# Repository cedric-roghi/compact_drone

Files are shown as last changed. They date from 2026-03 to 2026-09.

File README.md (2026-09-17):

# compact_drone
compact contra rotating drone

Progress Update (17/09/26):
- I have been making further tuning and tweaking to the PID gains.
- Built a simple landing gear system out of wood and a 3D printed adapter to screw onto the drone frame.
- I have got some first flight attempts with the drone hopping around the garden in a semi-controlled way.

https://github.com/user-attachments/assets/63424fa8-df9c-4474-a59d-4073fd4611da

Progress Update (09/09/26):
- The yaw controls are working. I have found some PID gains that seem stable at low and high rotor speeds. I am planning on making a PyQT application to adjust flight controller settings without flashing the microcontroller.
- I used hot glue to fix the servo motors more securely and printed some new link rods to reduce play in the swash-plate.
- The swash-plate currently has too much play where the drone cannot correct error when its too small and leads to uncontrollable oscillation.

https://github.com/user-attachments/assets/415317f5-2f4a-4eaa-9d52-048ebe863607

## Table of Contents
- [Requirements](#requirements)
- [Rationale](#rationale)
- [Installation](#installation)
- [Usage](#usage)
- [Features](#features)
- [Future_Additions](#future_additions)
- [Configuration](#configuration)
- [Known_Issues](#known_issues)

## Requirements
- Software:
    - Freecad (for 3D part design)
    - KICAD (PCB design)
    - ST Cube IDE (ST account required for download)
- Hardware:
    - BOM to come
    - Access to a 3D printer

## Rationale
I did not come up with the design idea of a tube shaped coaxial drone. Despite it being a rare design I got inspiration from projects such as [backcountrydrones](https://www.youtube.com/watch?v=82phDhYGT_0) and [Tdrone](https://github.com/ShenZhenAccelerationTechCo/Tdrone). BackcountryDrones guys have now changed to Ascent Aerosystems and make military/law enforcement and industrial coaxial drones. The NASA mars copter is another example of a contra rotating drone design.

The idea is that the propellers can fold down which means the drone can fit in smaller storage solutions. Not only does the the tube shape enable a smaller size when storing the drone but it also helps make it more rugged and resistant to poor treatment. A final goal for this project would be to have a drone I can strap to the outside of a hiking pack without having to worry about damage. 

Using a coaxial design is more efficient in theory. Having two large propeller spinning about the center of the drone increases the lifting disc area compared to having four propellers next to each other that will waste space. A coaxial drone with a tube shape also reduces its surface area when tilting forwards to move making it more streamlined than a quadcopter that shows more surface area to drag when moving forward. I recommend reading this paper from Ascent Aerosystems about all the advantages and its got diagrams (https://ascentaerosystems.com/wp-content/uploads/2024/12/Coaxial-Advantage-White-Paper-Ascent-AeroSystems.pdf).

Just because two propellers are stacked on top of each other does not actually mean I get double the lift of normal helicopter. Based on a small amount of research I have done, it would seem that while coaxial drones can be more efficient and reduce turbulent airflow they do not multiply thrust by two. Basically the thrust gain is not linear. Source (https://www.ligpower.com/blog/conventional-vs-coaxial-drone-motors.html).

Figures from the Ascent Aerosystems paper (https://ascentaerosystems.com/wp-content/uploads/2024/12/Coaxial-Advantage-White-Paper-Ascent-AeroSystems.pdf).



Some applications for the drone would be for survey work in remote areas, filming, compact and rapid deployment via stackable launch cells. In theory it could even be launched from a plane like the Atlantique 2 which already has tube shaped launchers on the belly for sonars. The mass plane launch system could enable for massive detailed search areas using drone swarms for any use case that would require a search area like pest control, mountain rescue, security perimeters.

Atlantique 2 sonar buoys launcher.
Sonar_Buoys_Launcher_of_Breguet_Atlantic

- STM32f411:
    - Same MCU I used for my turret project. Its fast, powerful, and has many timers for pwm output. Since I used it for a previous turret project it makes the PCB development for the drone much faster.
    - Another great advantage of this MCU is that it can do up to 100MHz clock speed which gives me plenty of headroom for "high speed"(relative term) communications like UART or I2C, without preempting my critical FreeRTOS tasks.

Below are some pictures of the PCB and 3D design to be printed.
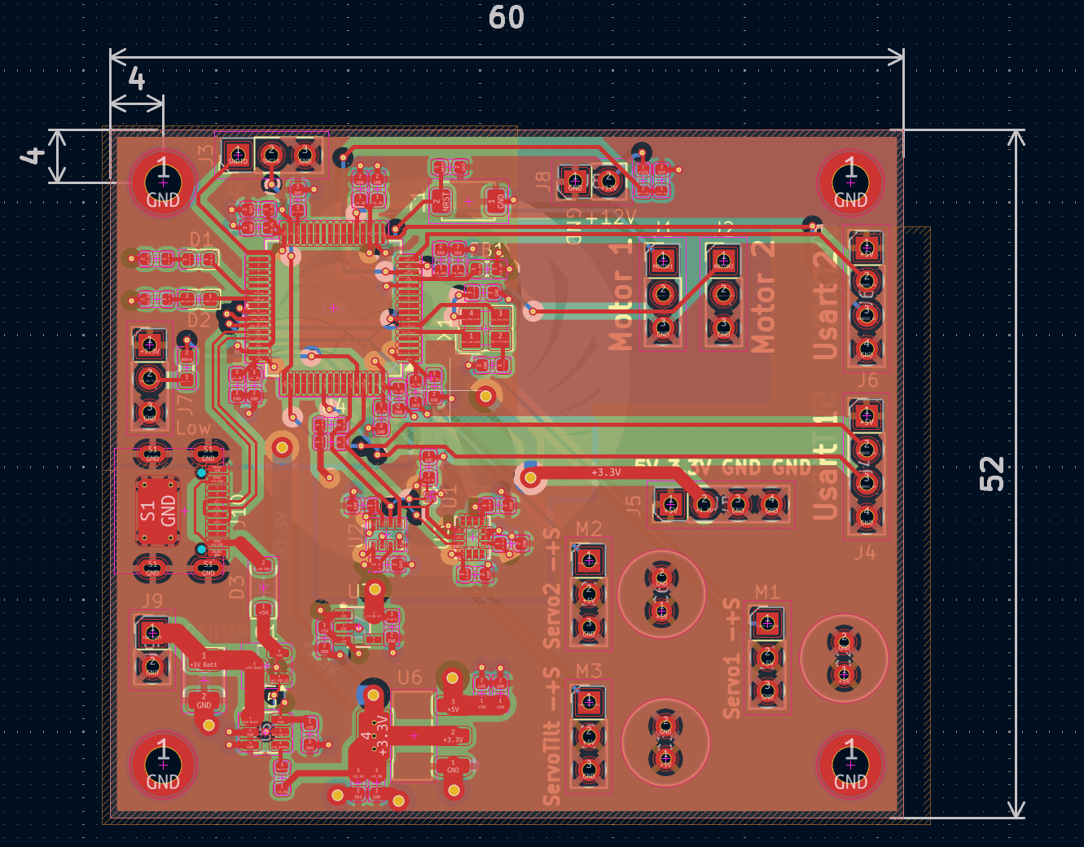
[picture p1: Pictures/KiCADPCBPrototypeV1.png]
Picture of Kicad PCB

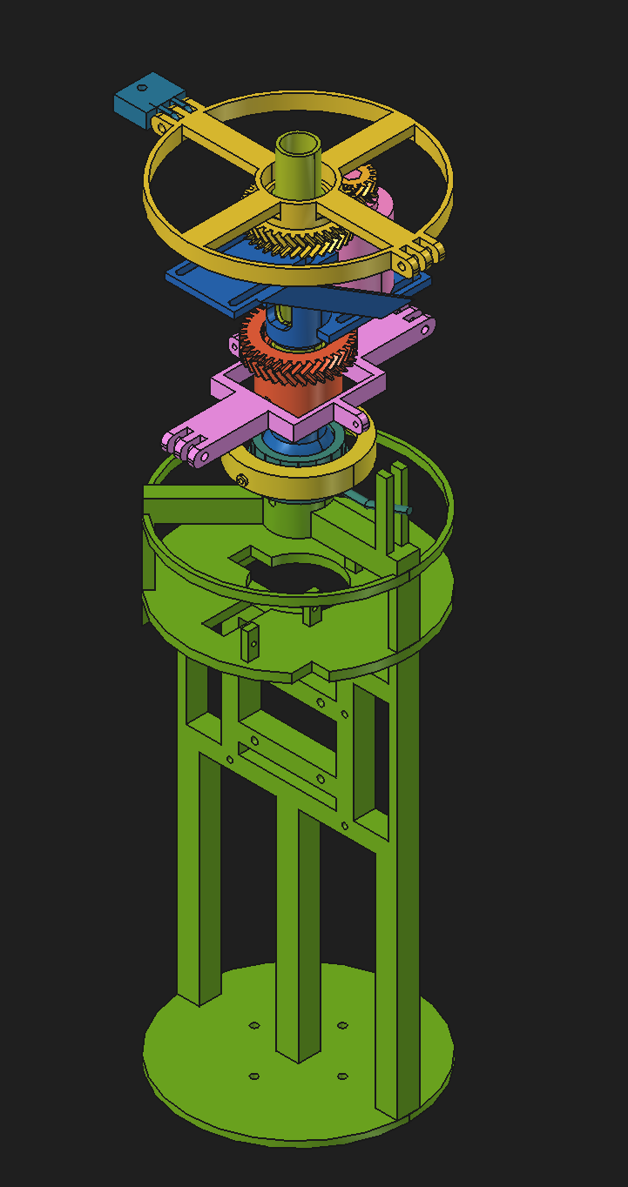
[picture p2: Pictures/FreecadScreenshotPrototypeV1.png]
Picture of FreeCAD design

electronics picture
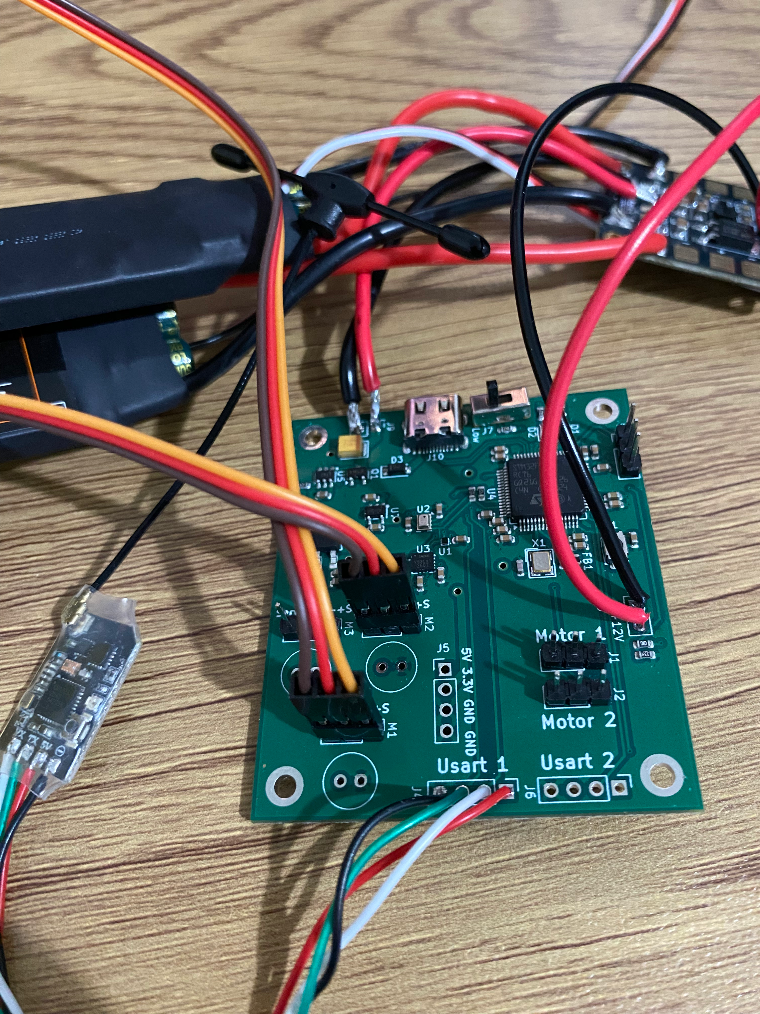
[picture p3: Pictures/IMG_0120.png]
electronics picture

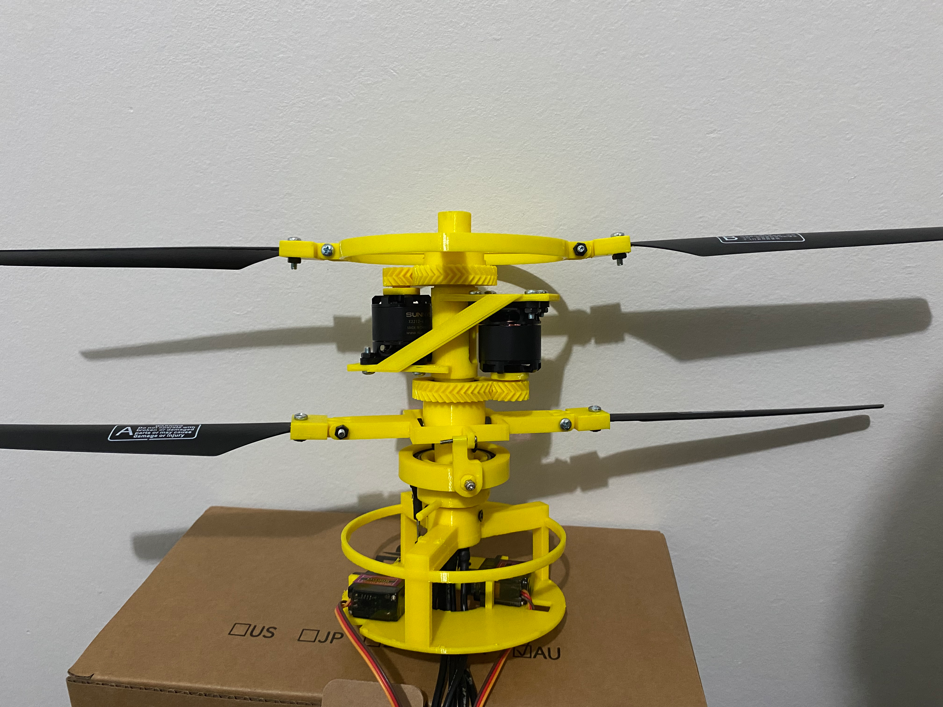
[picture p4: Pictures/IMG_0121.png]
electronics picture


## Installation
program command for usb in BOOT 0 mode

dfu-util -a 0 -s 0x08000000:leave -D build/debug/Drone_Code.bin

or use an stlinkv2.

## Usage

## Features
- Flight Controller
    -  ICM42605 IMU
    -  MMC5603NJ Magnetometer
    -  BMP280 Barometer
    -  2 USART connections for ELRS receiver and a future upgrade
    -  SWD connector for debugging/flashing
    -  Green and Red status LEDs
    -  BOOT0 switch (to switch bootloader mode)
    -  Reset button
    -  Extra servo PWM connector for camera pitch control (idea is that there is no need for yaw since the drone spins around easily)
 
- Mechanical
    - Foldable propellers
    - Fully 3D printed body
    - 
## Future_Additions

## Configuration

## Known_Issues

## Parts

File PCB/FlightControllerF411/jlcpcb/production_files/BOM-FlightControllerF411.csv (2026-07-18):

Comment | Designator | Footprint | LCSC | Quantity
100kΩ | R4 | R_0603 | C25803 | 1
100nF | C10,C13,C14,C15,C17,C19,C21,C22,C25,C30,C4,C5,C8 | C_0603 | C14663 | 13
100uF | C26 | C_CASE-B-3528-21(mm) | C16133 | 1
10k | R1 | R_0603_1608Metric_Pad0.98x0.95mm_HandSolder | C25805 | 1
10nF | C7 | C_0603 | C57112 | 1
10uF | C11,C27,C29,C31,C33 | C_0603 | C19702 | 5
18pF | C16,C18 | C_0603 | C1647 | 2
1uF | C23,C24,C28,C32 | C_0603 | C15849 | 4
2.2uF | C1,C9 | C_0603 | C23630 | 2
220Ω | R3 | R_0603 | C22962 | 1
270Ω | R2 | R_0603 | C22966 | 1
33kΩ | R5 | R_0603 | C4216 | 1
4.7kΩ | R6,R7 | R_0603 | C23162 | 2
4.7uF | C12,C20 | C_0603 | C19666 | 2
470kΩ | R8 | R_0603 | C23178 | 1
AMS1117 | U6 | SOT-223-3_L6.5-W3.4-P2.30-LS7.0-BR | C6186 | 1
AO3401A | Q1 | Q_SOT-23 | C15127 | 1
B5817W | D3 | D_SOD-123 | C7420328 | 1
BMP280 | U2 | Bosch_LGA-8_2x2.5mm_P0.65mm_ClockwisePinNumbering | C83291 | 1
Connector, USB-TYPE-C-16P | J10 | TYPE-C-SMD_HX-TYPE-C-16PIN | C2927039 | 1
ICM-42605 | U3 | LGA-14_L3.0-W2.5-P0.50-TL | C2655099 | 1
LTC4412xS6 | U5 | TSOT-23-6 | C514442 | 1
MMC5603NJ | U1 | FLIPCHIP-4_L0.8-W0.8-R2-C2-P0.40-TL | C404328 | 1
RT9013-33GB | U7 | SOT-23-5_L3.0-W1.7-P0.95-LS2.8-BL | C47773 | 1
STM32F411RCTx | U4 | LQFP-64_10x10mm_P0.5mm | C222222 | 1
Tactile Button, 160gf | S1 | SW_TS-1088-AR02016 | C720477 | 1
X322525MOB4SI | X1 | CRYSTAL-SMD_4P-L3.2-W2.5-BL | C9006 | 1
~ | FB1 | FB_0603 | C14709 | 1

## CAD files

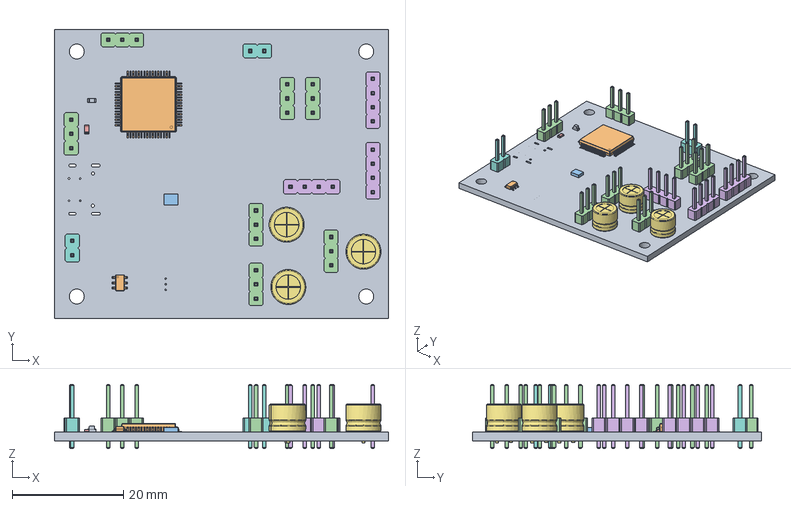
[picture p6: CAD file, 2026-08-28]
Mechanical/FlightControllerF.FCStd
60.0 x 52.0 x 11.5 mm
Pcb_b9f9
U4_LQFP-64_10x10mm_P0.5mm_fae24eecaddc
U2_Bosch_LGA_8_2x25mm_P065mm_ClockwisePinNumbering_f0a005fde938
J7_PinHeader_1x03_P254mm_Vertical_549c4d7b720a x 7
R1_R_0603_1608Metric_eb1ff95d47ac
J4_PinHeader_1x04_P254mm_Vertical_8452266c3579 x 3
C6_C_Radial_D63mm_H50mm_P250mm_8d51c2e56bce x 3
J8_PinHeader_1x02_P254mm_Vertical_0fda977fbcc8 x 2
D2_LED_0603_1608Metric_ebea01f88a53
U5_TSOT-23-6_ac6f2db5987e

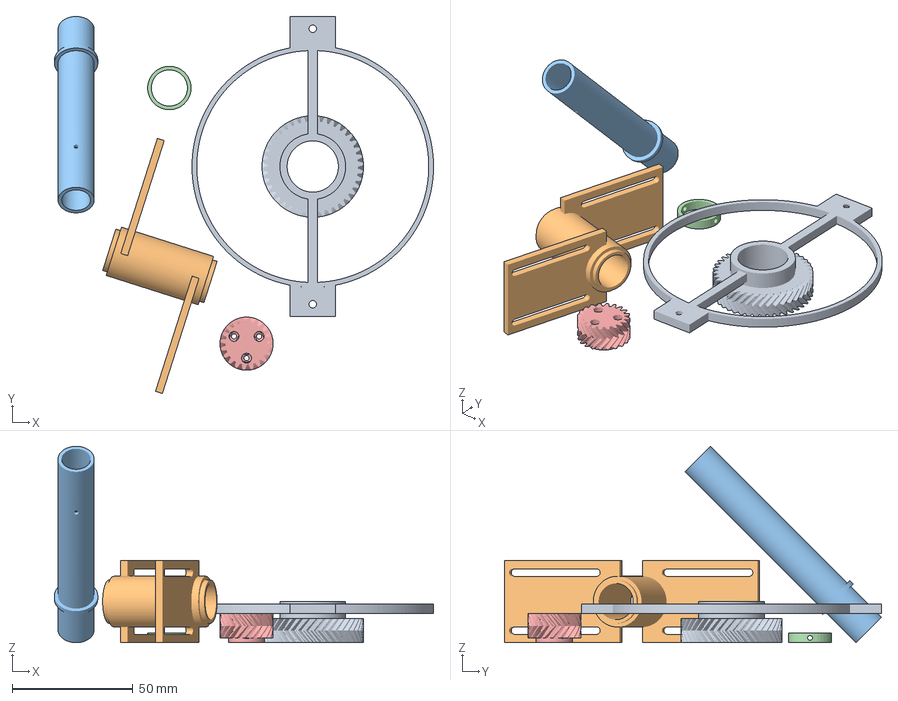
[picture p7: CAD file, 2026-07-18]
Mechanical/RotorShaftMechanical-Drone_Mechanical_UpperUpperGear.3mf
156.9 x 156.0 x 81.3 mm
RotorShaftMechanical-Drone_Mechanical_UpperUpperGear.stl
RotorShaftMechanical-Drone_Mechanical_UpperMotor Holder.stl
RotorShaftMechanical-Drone_Mechanical_UpperShaft.stl
RotorShaftMechanical-Drone_Mechanical_UpperBearingStopperUpper.stl
RotorShaftMechanical-Drone_Mechanical_UpperUpperMotorGear.stl

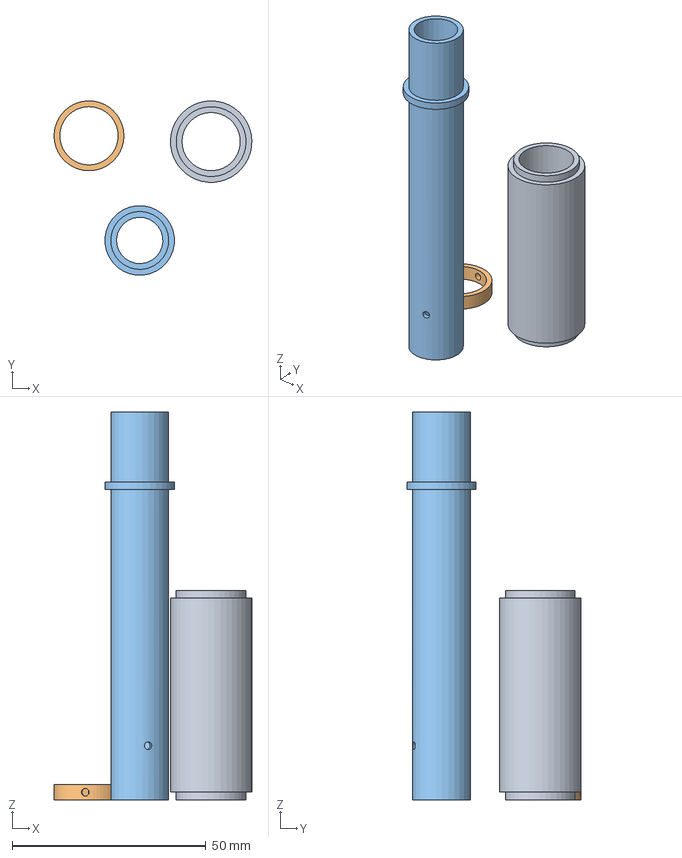
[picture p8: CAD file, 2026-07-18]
Mechanical/RotorShaftMechanical-Drone_Mechanical_UpperMotor Holder.3mf
51.0 x 44.9 x 100.0 mm
RotorShaftMechanical-Drone_Mechanical_UpperMotor Holder.stl
RotorShaftMechanical-Drone_Mechanical_UpperBearingStopperUpper.stl
RotorShaftMechanical-Drone_Mechanical_UpperShaft.stl

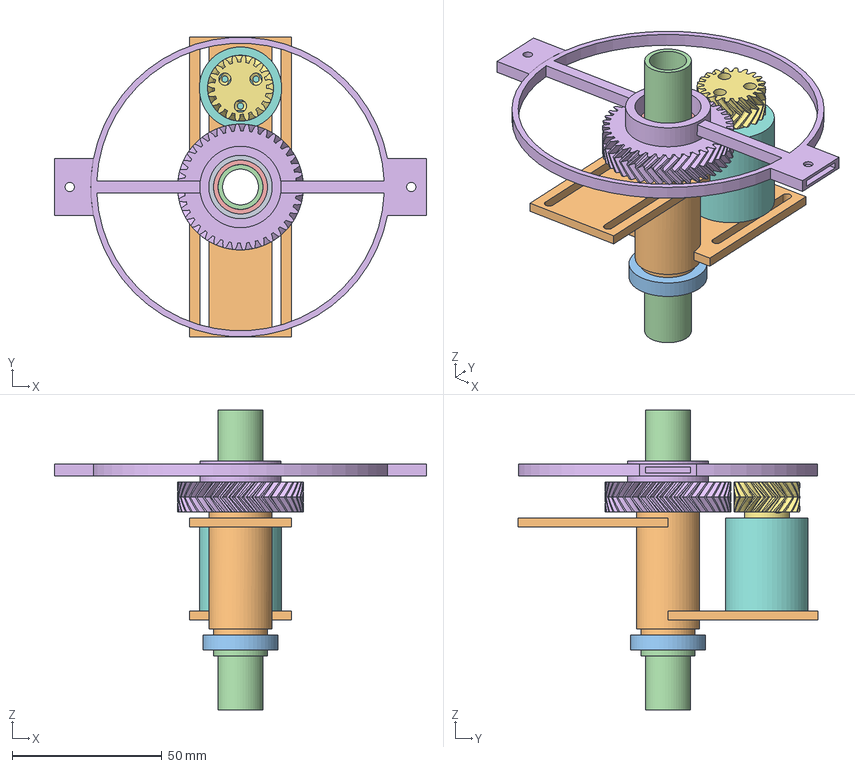
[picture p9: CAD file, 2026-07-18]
Mechanical/RotorShaftMechanical.FCStd
124.2 x 100.0 x 100.0 mm
BearingUpper
Motor Holder
BearingLower
Shaft
BearingStopperUpper
UpperGear
UpperMotorGear
Motor

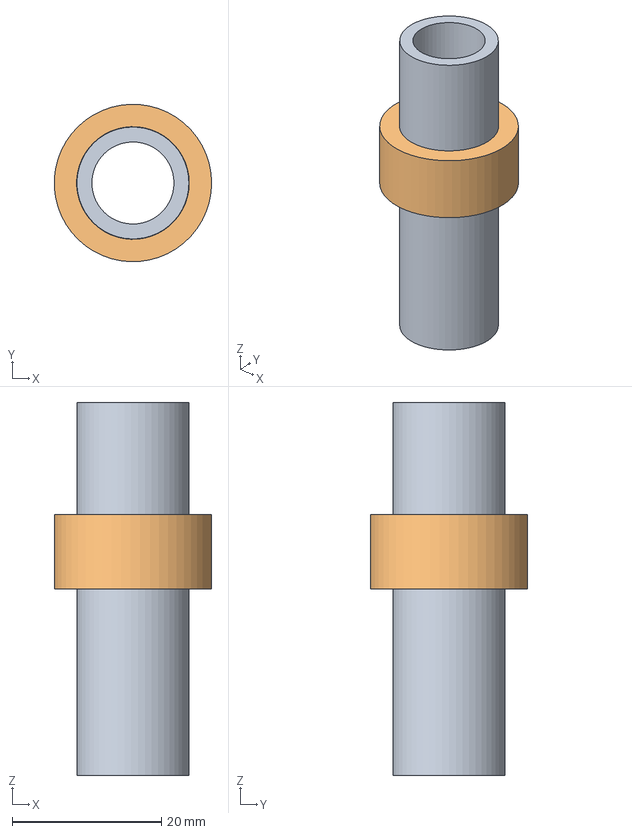
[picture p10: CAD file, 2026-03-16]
Mechanical/DroneDriveShaft.FCStd
21.1 x 21.1 x 50.0 mm
Main Shaft
BottomRotor

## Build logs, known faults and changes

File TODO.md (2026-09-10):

### Prototype V1 checklist

- ✅ PCB design done
- ✅ Drone mechanical structure done
- ✅ ELRS receiver connected and receiving
- ✅ Flight controller receiving packets from ELRS receiver
- ✅ ELRS transmitter receives telemetry packet from drone
- ✅ IMU (Just the accelerometer and gyroscope) is working and sensor fusion to get stable data
- ✅ Motor control file to limit motor operations within safe  physical ranges (ie. dont move servo more than swashplate can physically handle)
- 🚧 PID controllers for yaw, pitch and roll
- ⬜ Add magnetometer and barometer functionality to the flight controller code 
- ⬜ Persistent flight controller settings to be stored in stm32 flash memory
- ⬜ PyQT application to adjust flight controller settings without flashing the microcontroller.

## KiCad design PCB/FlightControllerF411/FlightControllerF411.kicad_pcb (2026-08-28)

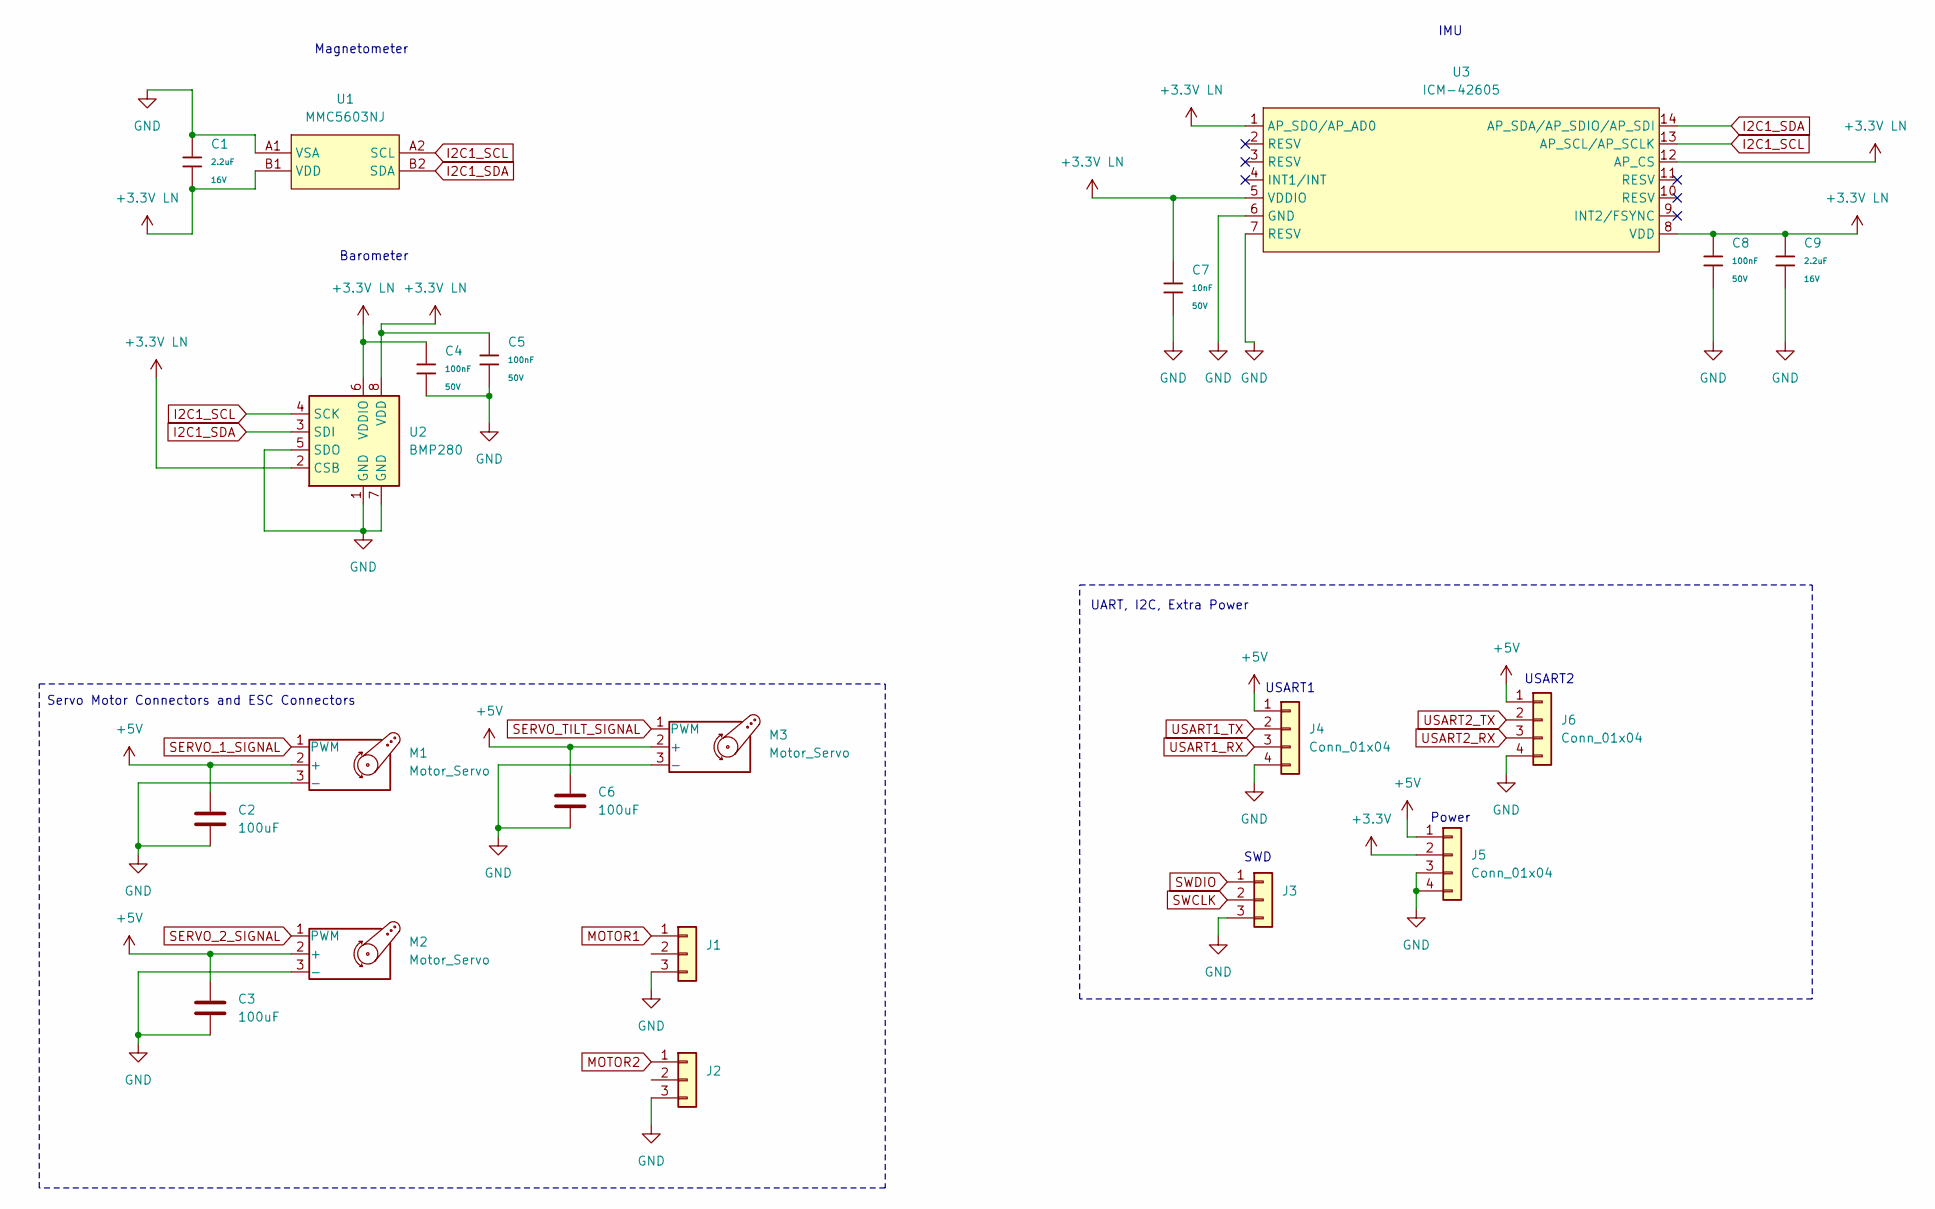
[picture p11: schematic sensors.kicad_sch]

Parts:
C1, C9: 2.2uF; C_0603; Voltage Rated 16V; Tolerance ±10%; Part CL10A225KO8NNNC; LCSC C23630
C2, C3, C6: 100uF; C_Radial_D6.3mm_H5.0mm_P2.50mm
C4, C5, C8: 100nF; C_0603; Voltage Rated 50V; Tolerance ±10%; Part CC0603KRX7R9BB104; LCSC C14663
C7: 10nF; C_0603; Voltage Rated 50V; Tolerance ±10%; Part 0603B103K500NT; LCSC C57112
J1, J2, J3: Conn_01x03; PinHeader_1x03_P2.54mm_Vertical
J4, J5, J6: Conn_01x04; PinHeader_1x04_P2.54mm_Vertical
M1, M2, M3: Motor_Servo; PinHeader_1x03_P2.54mm_Vertical
U1: MMC5603NJ; FLIPCHIP-4_L0.8-W0.8-R2-C2-P0.40-TL; MPN MMC5603NJ; LCSC Part C404328
U2: BMP280; Bosch_LGA-8_2x2.5mm_P0.65mm_ClockwisePinNumbering
U3: ICM-42605; LGA-14_L3.0-W2.5-P0.50-TL; MPN ICM-42605; LCSC Part C2655099

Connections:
+3.3V: J5.2; also elsewhere on the board
+3.3V LN: C1.2, C4.1, C5.1, C7.1, C8.1, C9.1, U1.B1 (VDD), U2.2 (CSB), U2.6 (VDDIO), U2.8 (VDD), U3.1 (AP_SDO/AP_AD0), U3.5 (VDDIO), U3.8 (VDD), U3.12 (AP_CS); also elsewhere on the board
+5V: C2.1, C3.1, C6.1, J4.1, J5.1, J6.1, M1.2 (+), M2.2 (+), M3.2 (+); also elsewhere on the board
GND: C1.1, C2.2, C3.2, C4.2, C5.2, C6.2, C7.2, C8.2, C9.2, J1.3, J2.3, J3.3, J4.4, J5.3, J5.4, J6.4, M1.3 (-), M2.3 (-), M3.3 (-), U1.A1 (VSA), U2.1 (GND), U2.5 (SDO), U2.7 (GND), U3.6 (GND), U3.7 (RESV); also elsewhere on the board
I2C1_SCL: U1.A2 (SCL), U2.4 (SCK), U3.13 (AP_SCL/AP_SCLK); also elsewhere on the board
I2C1_SDA: U1.B2 (SDA), U2.3 (SDI), U3.14 (AP_SDA/AP_SDIO/AP_SDI); also elsewhere on the board
MOTOR1: J1.1; also elsewhere on the board
MOTOR2: J2.1; also elsewhere on the board
SERVO_1_SIGNAL: M1.1 (PWM); also elsewhere on the board
SERVO_2_SIGNAL: M2.1 (PWM); also elsewhere on the board
SERVO_TILT_SIGNAL: M3.1 (PWM); also elsewhere on the board
SWCLK: J3.2; also elsewhere on the board
SWDIO: J3.1; also elsewhere on the board
USART1_RX: J4.3; also elsewhere on the board
USART1_TX: J4.2; also elsewhere on the board
USART2_RX: J6.3; also elsewhere on the board
USART2_TX: J6.2; also elsewhere on the board

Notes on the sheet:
USART1
Servo Motor Connectors and ESC Connectors
UART, I2C, Extra Power
Power
SWD
Magnetometer
Barometer
IMU
USART2

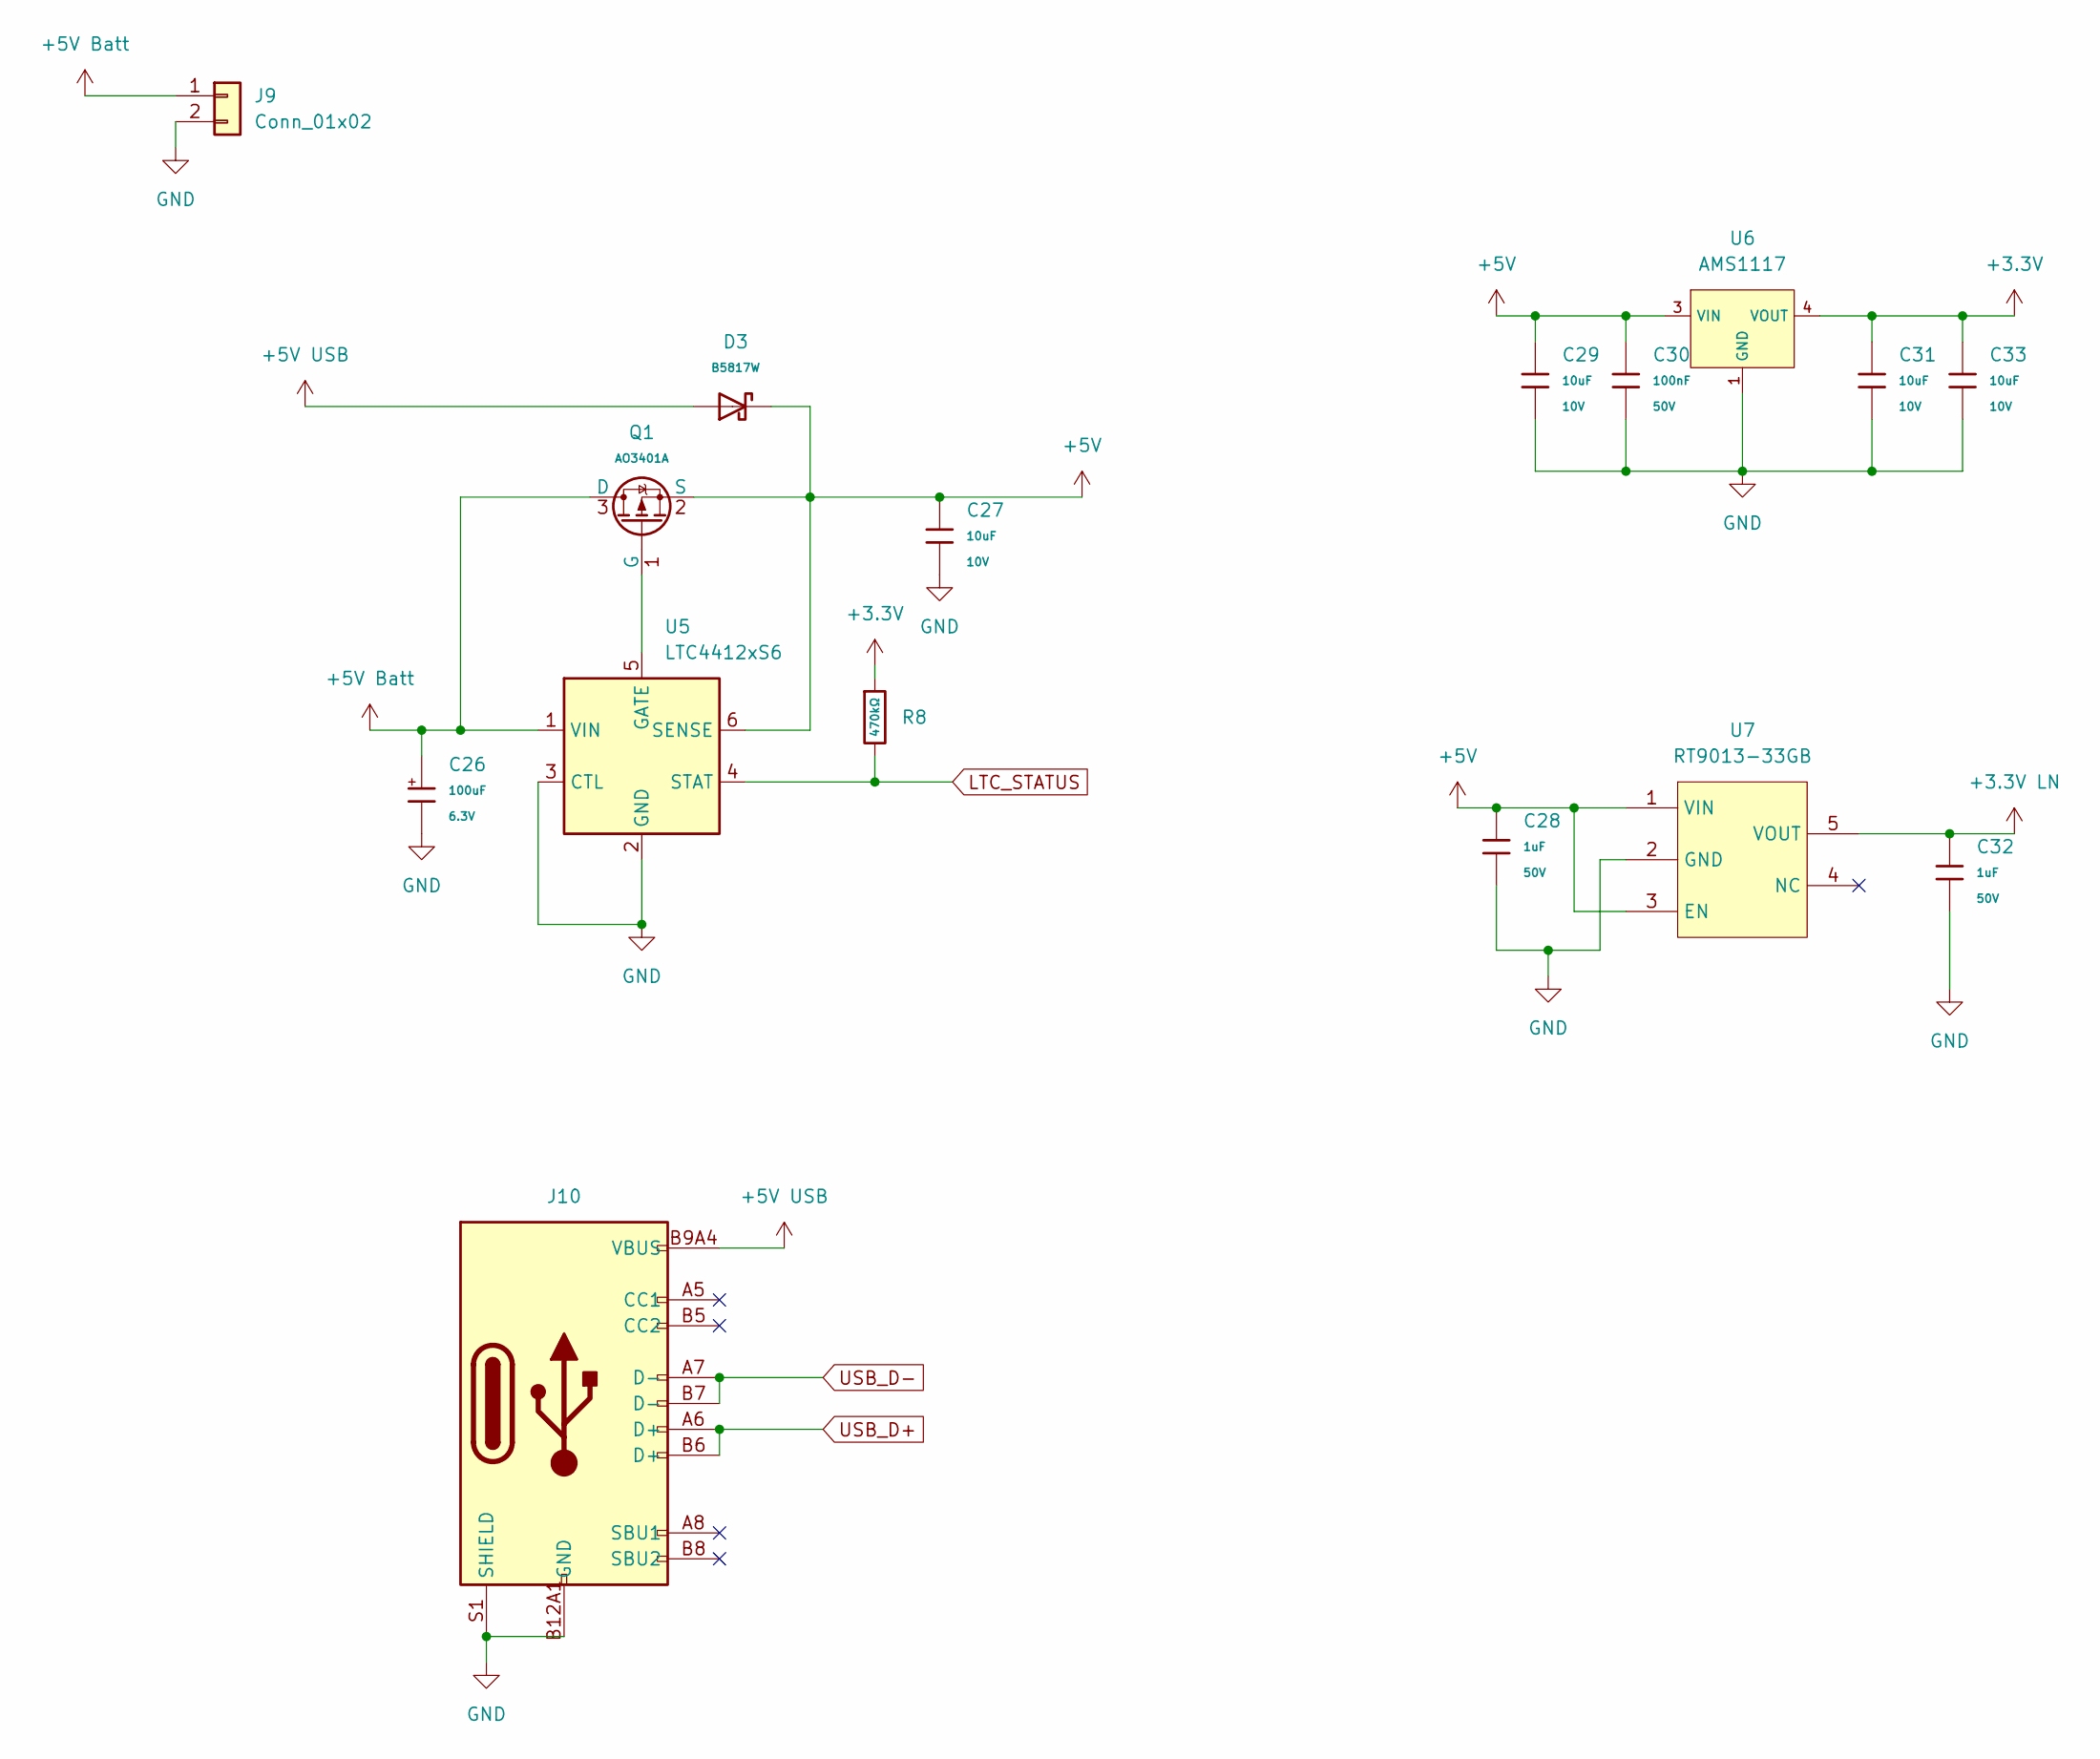
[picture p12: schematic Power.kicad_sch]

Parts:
C26: 100uF; C_CASE-B-3528-21(mm); Tolerance ±10%; Rated Voltage 6.3V; Part TAJB107K006RNJ; LCSC C16133
C27, C29, C31, C33: 10uF; C_0603; Voltage Rated 10V; Tolerance ±10%; Part CL10A106KP8NNNC; LCSC C19702
C28, C32: 1uF; C_0603; Voltage Rated 50V; Tolerance ±10%; Part CL10A105KB8NNNC; LCSC C15849
C30: 100nF; C_0603; Voltage Rated 50V; Tolerance ±10%; Part CC0603KRX7R9BB104; LCSC C14663
D3: B5817W; D_SOD-123; Forward Voltage (Vf@If) 0.45V@1.0A; Reverse Voltage (Vr) 20V; Part B5817W; LCSC C7420328
J9: Conn_01x02; PinHeader_1x02_P2.54mm_Vertical
J10: Connector, USB-TYPE-C-16P; TYPE-C-SMD_HX-TYPE-C-16PIN; LCSC C2927039
Q1: AO3401A; Q_SOT-23; Part AO3401A; LCSC C15127
R8: 470kΩ; R_0603; Overload Voltage (Max) 75V; Tolerance ±1%; Part 0603WAF4703T5E; LCSC C23178
U5: LTC4412xS6; TSOT-23-6
U6: AMS1117; SOT-223-3_L6.5-W3.4-P2.30-LS7.0-BR; Output Voltage 3.3V; Dropout Voltage 1.3V@(800mA); Part AMS1117-3.3; LCSC C6186
U7: RT9013-33GB; SOT-23-5_L3.0-W1.7-P0.95-LS2.8-BL; MPN RT9013-33GB; LCSC Part C47773

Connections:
+3.3V: C31.1, C33.1, R8.1, U6.2 (VOUT), U6.4 (VOUT); also elsewhere on the board
+3.3V LN: C32.1, U7.5 (VOUT); also elsewhere on the board
+5V: C27.1, C28.1, C29.1, C30.1, D3.1, Q1.2 (S), U5.6 (SENSE), U6.3 (VIN), U7.1 (VIN), U7.3 (EN); also elsewhere on the board
+5V Batt: C26.1, J9.1, Q1.3 (D), U5.1 (VIN)
+5V USB: D3.2, J10.A9B4 (VBUS), J10.B9A4 (VBUS)
GND: C26.2, C27.2, C28.2, C29.2, C30.2, C31.2, C32.2, C33.2, J9.2, J10.A12B1 (GND), J10.B12A1 (GND), J10.S1 (SHIELD), U5.2 (GND), U5.3 (CTL), U6.1 (GND), U7.2 (GND); also elsewhere on the board
LTC_STATUS: R8.2, U5.4 (STAT)
unnamed: Q1.1 (G), U5.5 (GATE)
USB_D+: J10.A6 (D+), J10.B6 (D+); also elsewhere on the board
USB_D-: J10.A7 (D-), J10.B7 (D-); also elsewhere on the board

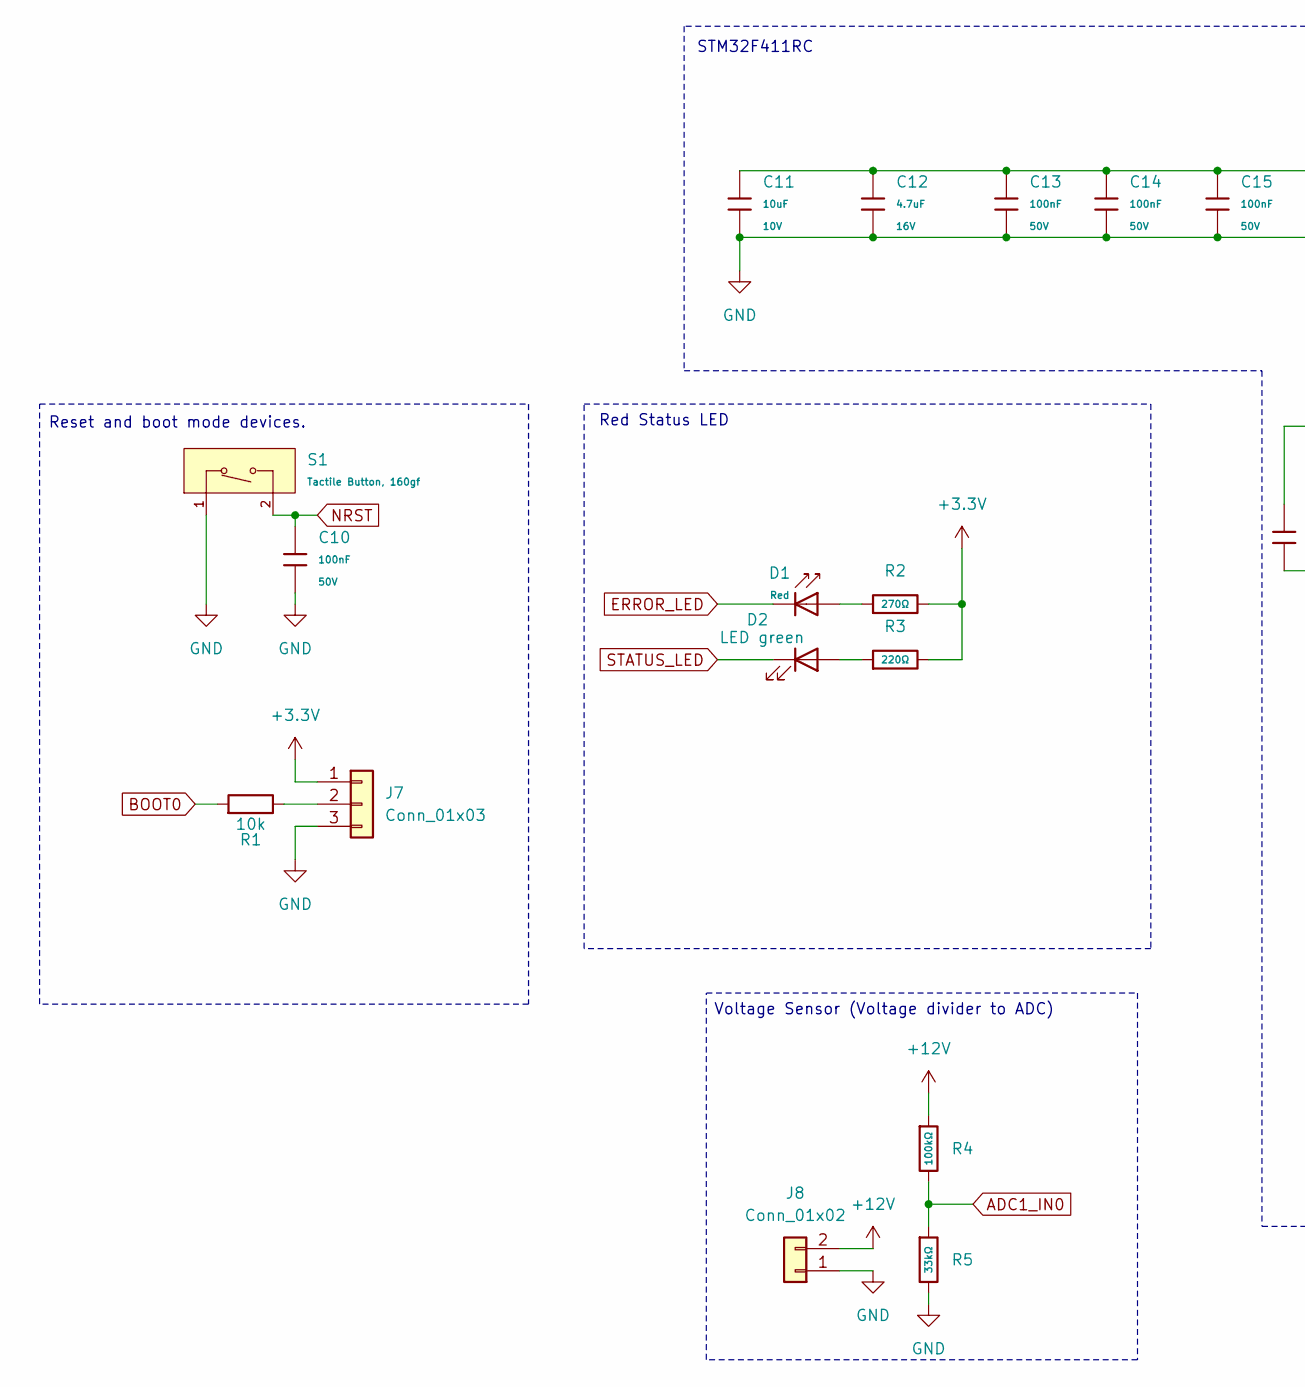
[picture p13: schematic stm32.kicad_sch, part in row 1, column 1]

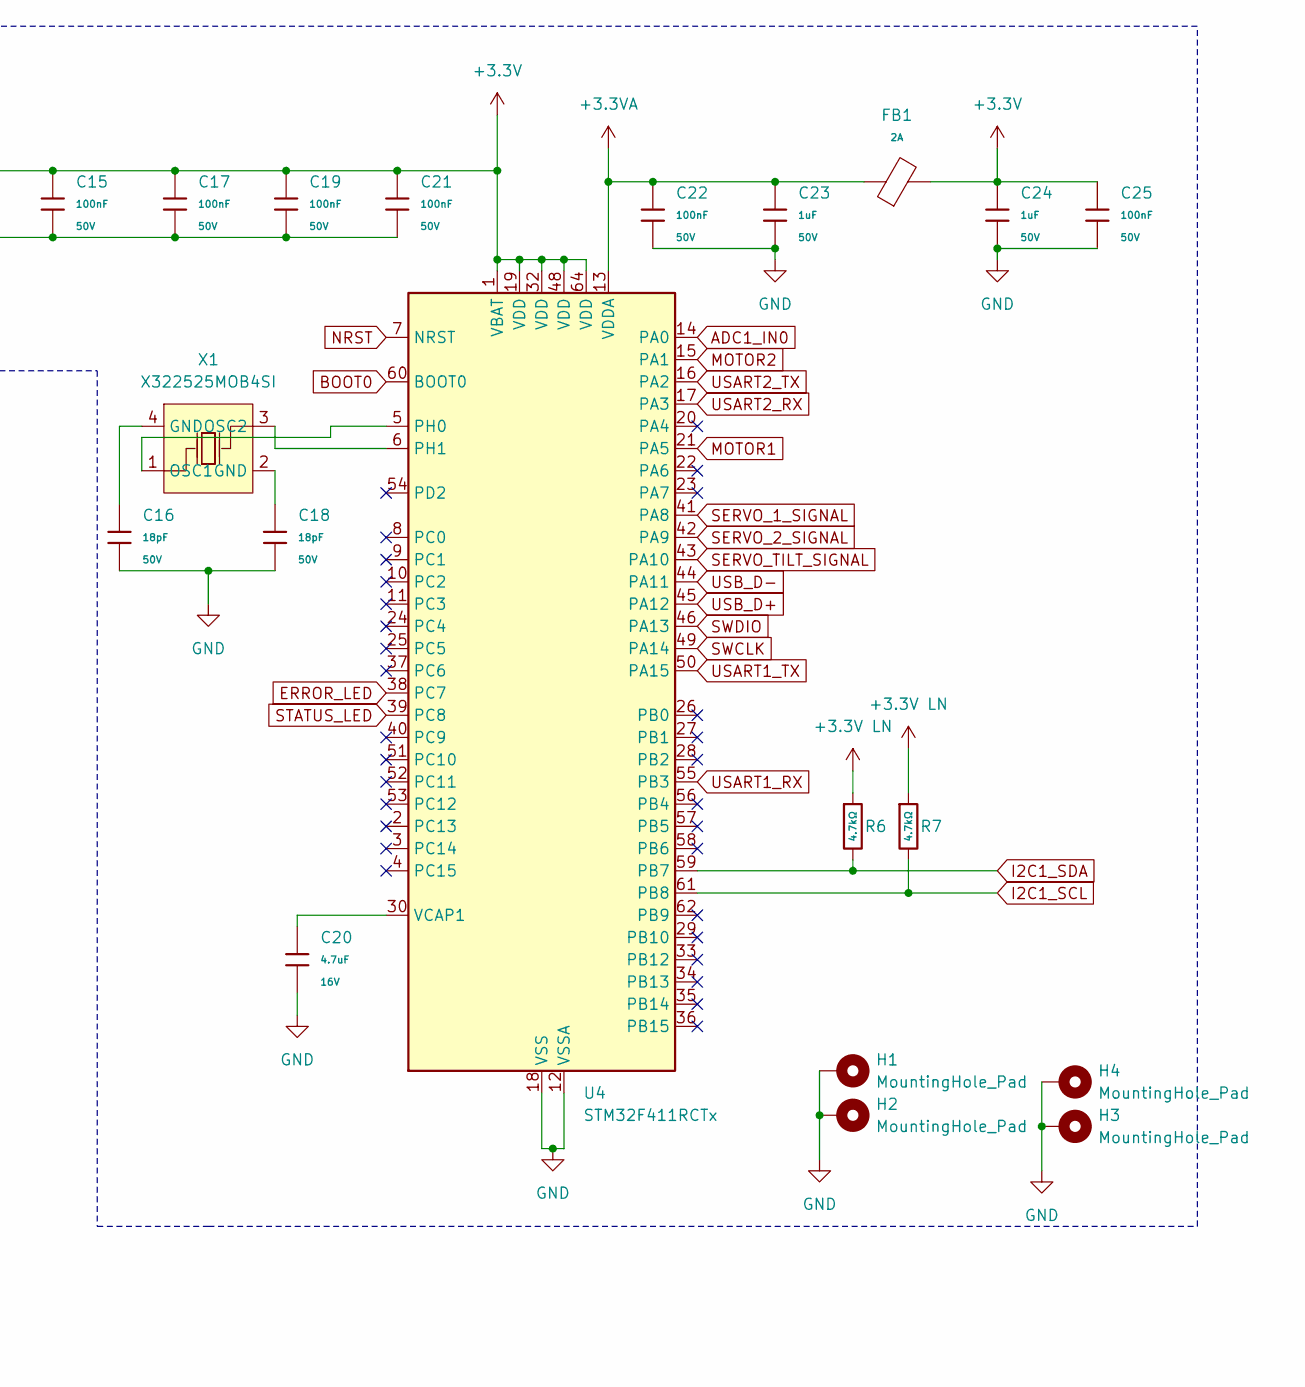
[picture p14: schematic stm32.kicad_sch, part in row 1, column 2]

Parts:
C10, C13, C14, C15, C17, C19, C21, C22, C25: 100nF; C_0603; Voltage Rated 50V; Tolerance ±10%; Part CC0603KRX7R9BB104; LCSC C14663
C11: 10uF; C_0603; Voltage Rated 10V; Tolerance ±10%; Part CL10A106KP8NNNC; LCSC C19702
C12, C20: 4.7uF; C_0603; Voltage Rated 16V; Tolerance ±10%; Part CL10A475KO8NNNC; LCSC C19666
C16, C18: 18pF; C_0603; Voltage Rated 50V; Tolerance ±5%; Part CL10C180JB8NNNC; LCSC C1647
C23, C24: 1uF; C_0603; Voltage Rated 50V; Tolerance ±10%; Part CL10A105KB8NNNC; LCSC C15849
D1: Red; D_0603; Part KT-0603R; LCSC C2286
D2: LED green; LED_0603_1608Metric_Pad1.05x0.95mm_HandSolder
FB1: FB_0603; Current Rating 2A; Tolerance ±25%; Part BLM18PG121SN1D; LCSC C14709
H1, H2, H3, H4: MountingHole_Pad; MountingHole_2.7mm_M2.5_DIN965_Pad
J7: Conn_01x03; PinHeader_1x03_P2.54mm_Vertical
J8: Conn_01x02; PinHeader_1x02_P2.54mm_Vertical
R1: 10k; R_0603_1608Metric_Pad0.98x0.95mm_HandSolder
R2: 270Ω; R_0603; Overload Voltage (Max) 75V; Tolerance ±1%; Part 0603WAF2700T5E; LCSC C22966
R3: 220Ω; R_0603; Overload Voltage (Max) 75V; Tolerance ±1%; Part 0603WAF2200T5E; LCSC C22962
R4: 100kΩ; R_0603; Overload Voltage (Max) 75V; Tolerance ±1%; Part 0603WAF1003T5E; LCSC C25803
R5: 33kΩ; R_0603; Overload Voltage (Max) 75V; Tolerance ±1%; Part 0603WAF3302T5E; LCSC C4216
R6, R7: 4.7kΩ; R_0603; Overload Voltage (Max) 75V; Tolerance ±1%; Part 0603WAF4701T5E; LCSC C23162
S1: Tactile Button, 160gf; SW_TS-1088-AR02016; Voltage Rating (Dc) 12V; Part TS-1088-AR02016; LCSC C720477
U4: STM32F411RCTx; LQFP-64_10x10mm_P0.5mm
X1: X322525MOB4SI; CRYSTAL-SMD_4P-L3.2-W2.5-BL; MPN X322525MOB4SI; LCSC Part C9006

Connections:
+3.3V: C11.1, C12.1, C13.1, C14.1, C15.1, C17.1, C19.1, C21.1, C24.1, C25.1, FB1.2, J7.1, R2.2, R3.2, U4.1 (VBAT), U4.19 (VDD), U4.32 (VDD), U4.48 (VDD), U4.64 (VDD); also elsewhere on the board
+3.3V LN: R6.1, R7.1; also elsewhere on the board
+3.3VA: C22.1, C23.1, FB1.1, U4.13 (VDDA)
+12V: J8.2, R4.1
ADC1_IN0: R4.2, R5.1, U4.14 (PA0)
BOOT0: R1.2, U4.60 (BOOT0)
ERROR_LED: D1.1, U4.38 (PC7)
GND: C10.2, C11.2, C12.2, C13.2, C14.2, C15.2, C16.2, C17.2, C18.2, C19.2, C20.2, C21.2, C22.2, C23.2, C24.2, C25.2, H1.1 (1_1), H2.1 (1_1), H3.1 (1_1), H4.1 (1_1), J7.3, J8.1, R5.2, S1.1 (A), U4.12 (VSSA), U4.18 (VSS), U4.31 (VSS), U4.47 (VSS), U4.63 (VSS); also elsewhere on the board
I2C1_SCL: R7.2, U4.61 (PB8); also elsewhere on the board
I2C1_SDA: R6.2, U4.59 (PB7); also elsewhere on the board
MOTOR1: U4.21 (PA5); also elsewhere on the board
MOTOR2: U4.15 (PA1); also elsewhere on the board
NRST: C10.1, S1.2 (B), U4.7 (NRST)
unnamed: C16.1, X1.4 (GND)
unnamed: C18.1, X1.2 (GND)
unnamed: D1.2, R2.1
unnamed: D2.2 (A), R3.1
unnamed: J7.2, R1.1
unnamed: U4.5 (PH0), X1.1 (OSC1)
unnamed: U4.6 (PH1), X1.3 (OSC2)
unnamed: C20.1, U4.30 (VCAP1)
SERVO_1_SIGNAL: U4.41 (PA8); also elsewhere on the board
SERVO_2_SIGNAL: U4.42 (PA9); also elsewhere on the board
SERVO_TILT_SIGNAL: U4.43 (PA10); also elsewhere on the board
STATUS_LED: D2.1 (K), U4.39 (PC8)
SWCLK: U4.49 (PA14); also elsewhere on the board
SWDIO: U4.46 (PA13); also elsewhere on the board
USART1_RX: U4.55 (PB3); also elsewhere on the board
USART1_TX: U4.50 (PA15); also elsewhere on the board
USART2_RX: U4.17 (PA3); also elsewhere on the board
USART2_TX: U4.16 (PA2); also elsewhere on the board
USB_D+: U4.45 (PA12); also elsewhere on the board
USB_D-: U4.44 (PA11); also elsewhere on the board

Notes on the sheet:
Red Status LED
STM32F411RC
Voltage Sensor (Voltage divider to ADC)
Reset and boot mode devices.

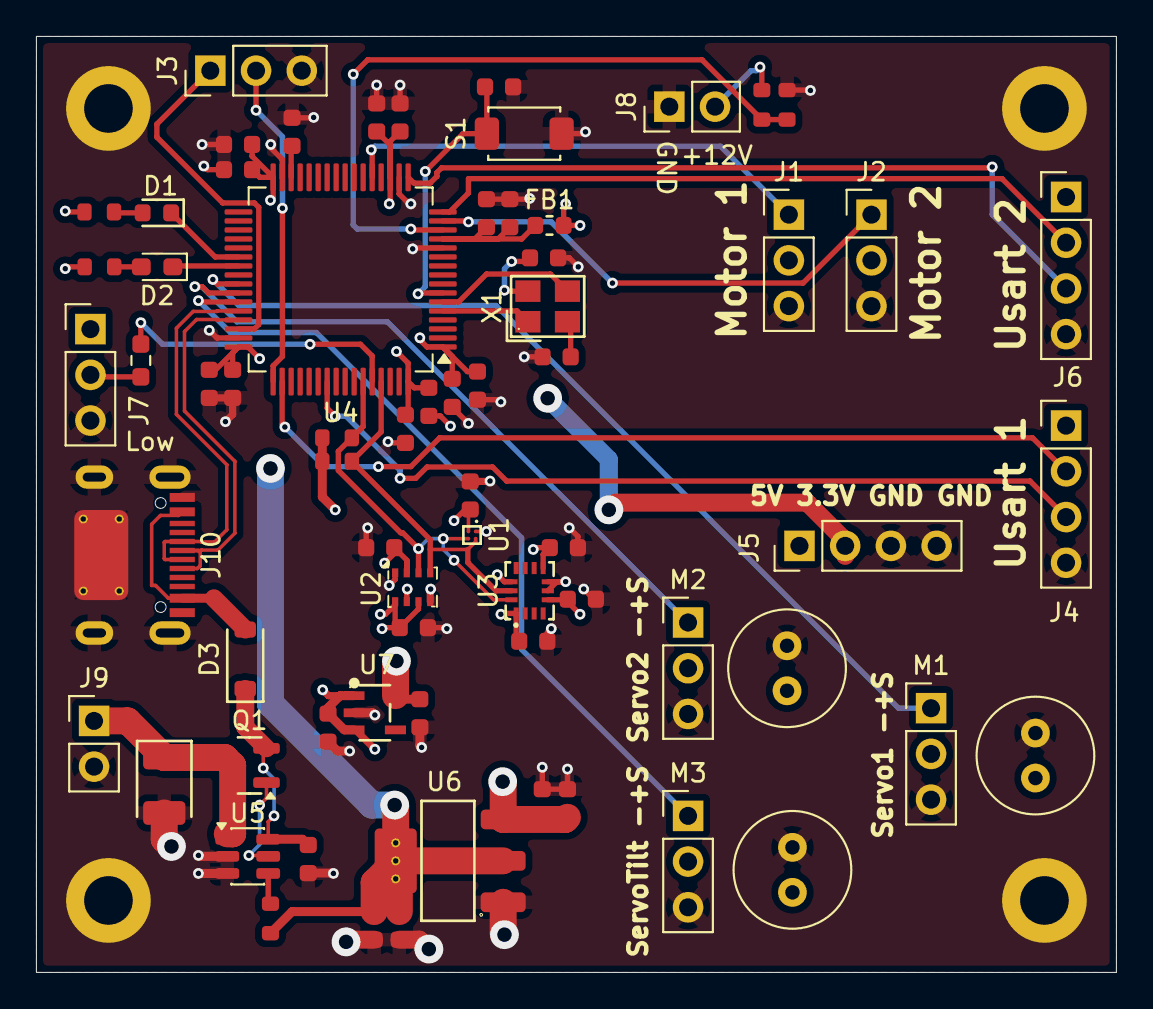
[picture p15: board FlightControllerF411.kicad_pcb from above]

Board: 4 copper layers, 60.0 x 52.0 mm, 72 parts (0 on the bottom side), 38 nets.

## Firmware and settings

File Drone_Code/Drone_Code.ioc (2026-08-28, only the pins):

Mcu.UserName=STM32F411RCTx
PA0-WKUP.Signal=ADCx_IN0
PA1.GPIO_Label=Motor 2
PA1.Signal=S_TIM2_CH2
PA10.GPIO_Label=Servo Tilt
PA10.Signal=S_TIM1_CH3
PA11.Signal=USB_OTG_FS_DM
PA12.Signal=USB_OTG_FS_DP
PA13.Signal=SYS_JTMS-SWDIO
PA14.Signal=SYS_JTCK-SWCLK
PA15.Signal=USART1_TX
PA2.Signal=USART2_TX
PA3.Signal=USART2_RX
PA5.GPIO_Label=Motor 1
PA5.Signal=S_TIM2_CH1_ETR
PA8.GPIO_Label=Servo 1
PA8.Signal=S_TIM1_CH1
PA9.GPIO_Label=Servo 2
PA9.Signal=S_TIM1_CH2
PB3.Signal=USART1_RX
PB7.Signal=I2C1_SDA
PB8.Signal=I2C1_SCL
PC7.Signal=GPIO_Output
PC8.Signal=GPIO_Output

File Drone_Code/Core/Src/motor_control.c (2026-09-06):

#include "motor_control.h"
#include <stdint.h>

// Initialize motor (assumes TIM1 is already configured for PWM)
void motor_Init(Motor *motor, uint32_t default_pulse_tick, uint32_t min_pulse_tick, uint32_t max_pulse_tick, TIM_HandleTypeDef *htim, uint32_t channel) {
    motor->htim = htim;
    motor->channel = channel;
    motor->default_pulse_tick = default_pulse_tick;
    motor->min_pulse =  min_pulse_tick;
    motor->max_pulse = max_pulse_tick;
}

// Set motor angle (0° to 180°) with instance-specific calibration limits
void servo_SetAngle(Motor *motor, float angle) {
    // 1. Structural Guardrails
    if (angle < 0.0f)   angle = 0.0f;
    if (angle > 180.0f) angle = 180.0f;

    // 2. Calculate pulse width using the instance limits instead of global macros
    uint32_t pulse = motor->min_pulse + (uint32_t)((angle / 180.0f) * (motor->max_pulse - motor->min_pulse));
    
    // 3. Update the hardware register
    __HAL_TIM_SET_COMPARE(motor->htim, motor->channel, pulse);
}

void motor_SetPulse(Motor *motor, uint32_t pulse_ticks)
{
    // Optional: Clamp the pulse value to your safe limits to prevent out-of-bounds register values
    if (pulse_ticks < motor->min_pulse) {
        pulse_ticks = motor->min_pulse;
    } else if (pulse_ticks > motor->max_pulse) {
        pulse_ticks = motor->max_pulse;
    }

    // Update the timer compare register directly
    __HAL_TIM_SET_COMPARE(motor->htim, motor->channel, pulse_ticks);
}

// Start motor PWM
void motor_Start(Motor *motor) {
    HAL_TIM_PWM_Start(motor->htim, motor->channel);
}

// Stop motor PWM
void motor_Stop(Motor *motor) {
    HAL_TIM_PWM_Stop(motor->htim, motor->channel);
}

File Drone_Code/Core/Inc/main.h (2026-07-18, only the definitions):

#define Motor_2_Pin GPIO_PIN_1
#define Motor_2_GPIO_Port GPIOA
#define Motor_1_Pin GPIO_PIN_5
#define Motor_1_GPIO_Port GPIOA
#define Servo_1_Pin GPIO_PIN_8
#define Servo_1_GPIO_Port GPIOA
#define Servo_2_Pin GPIO_PIN_9
#define Servo_2_GPIO_Port GPIOA
#define Servo_Tilt_Pin GPIO_PIN_10
#define Servo_Tilt_GPIO_Port GPIOA

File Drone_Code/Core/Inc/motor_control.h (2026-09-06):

#ifndef MOTOR_CONTROL_H
#define MOTOR_CONTROL_H

#include "stm32f4xx_hal.h"

// Motor pulse width in timer ticks (Configured for a 1 MHz timer clock)
// This gives a 1 microsecond resolution per tick, yielding 1000 steps of precision!
#define SERVO_MIN_PULSE_TICKS 1200   // 60 degrees (90° - 30°)
#define SERVO_MID_PULSE_TICKS 1500   // 90 degrees (Center)
#define SERVO_MAX_PULSE_TICKS 1800   // 120 degrees (90° + 30°)

#define ESC_MIN_PULSE_TICKS 16000   // 1.0ms pulse (0%)
#define ESC_MAX_PULSE_TICKS 32000   // 2.0ms pulse (100%)

// Motor structureS
typedef struct {
    TIM_HandleTypeDef *htim;
    uint32_t channel;
    uint32_t default_pulse_tick;
    uint32_t min_pulse;
    uint32_t max_pulse;
} Motor;

// Function prototypes
void motor_Init(Motor *motor, uint32_t default_pulse_tick, uint32_t min_pulse_tick, uint32_t max_pulse_tick, TIM_HandleTypeDef *htim, uint32_t channel);
void motor_SetAngle(Motor *motor, float angle); // Angle from 0.0 to 180.0
void motor_SetPulse(Motor *motor, uint32_t pulse_ticks);
void motor_Start(Motor *motor);
void motor_Stop(Motor *motor);

#endif // MOTOR_CONTROL_H

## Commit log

2026-03-16 small commit to put things back to date
    [DroneDriveShaft.FCStd]
2026-07-18 flight controller board is done, started working on the code, started work on the mechanical
    [BOM-FlightControllerF411.csv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]
2026-08-06 working elrs packets and some new mechanical parts
    [RotorShaftMechanical-Drone_Mechanical_UpperBearingStopperUpper.stl, RotorShaftMechanical-Drone_Mechanical_UpperGearUpper.3mf, RotorShaftMechanical-Drone_Mechan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]
2026-08-28 Did some README work
    [FlightControllerF.FCStd, FlightControllerF411.kicad_pcb, GearLowerPropHolder.3mf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]
2026-09-06 working code sort of pid is going
    [RotorShaftMechanical-Drone_Mechanical_UpperBladeHolder.3mf, Swashplate.3mf]
2026-09-06 fixed battery telemetry problems
2026-09-07 fixed yaw problems
2026-09-08 trying to get pid properly tuned
2026-09-09 yaw PID control is now tuned
    [RotorShaftMechanical-Drone_Mechanical_UpperGearUpper.3mf]
2026-09-16 cleaning the git pt2
    [GearLowerPropHolder.3mf, GearMotor.3mf, RotorShaftMechanical-Drone_Mechanical_UpperBladeHolder.3mf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]

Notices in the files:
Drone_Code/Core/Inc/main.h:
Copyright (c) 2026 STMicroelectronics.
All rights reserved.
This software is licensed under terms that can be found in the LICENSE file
